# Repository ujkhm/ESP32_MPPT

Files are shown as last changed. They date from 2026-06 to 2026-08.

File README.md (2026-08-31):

# 微型發電機測試機 / Micro Generator Test Machine

以 **ESP32** 為核心的小型有刷直流發電機**特性量測機台**，不是 MPPT 控制器。

主動力 775 馬達把待測發電機帶到指定轉速後，依序量測連續安全電流、內阻與開路常數，再算出固定測試電阻上的功率曲線與可用轉速上限，上位機可存成 PDF 報表。

## 倉庫結構

```
micro-generator-test-machine
├── 3D_print_Component/   變速箱與機構 3D 模型（外殼 STL 另補）
├── BOM/                  元件清單與互動式 BOM
├── KiCad/                原理圖、PCB、Gerber
├── VSCode/esp32_code/    ESP32 韌體（PlatformIO）
└── Host computer/        免安裝上位機執行檔與說明
```

各資料夾內另有說明。

## 上位機

`Host computer/MicroGeneratorHost.exe` 免安裝。複製該資料夾到 Windows 電腦，雙擊執行，依畫面以藍牙連接下位機即可測試。詳見 [Host computer/README.md](./Host%20computer/README.md)。

## 目前狀態

- 電路與 PCB：完成（見 `KiCad/`、`BOM/`）
- 韌體量測流程：完成（安全電流、內阻、曲線）
- 上位機：完成（藍牙監控與 PDF 報表）
- 外殼：待補 STL

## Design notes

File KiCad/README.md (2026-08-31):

## KiCad

本專案電路使用KiCad 9做開發，無修改原理圖/PCB需求的可以直接使用資料夾內的Gerber.zip檔直接提交給板廠製板<br><br>
附上原理突及PCB快照<br>
[原理圖](images/KiCad.pdf)<br>
[PCB](images/KiCad_PCB.pdf)<br>
建議下載後用 PDF 檢視工具開啟。快照位於 `KiCad/images/`。
另有BOM表單位於BOM資料夾下[點我前往](../BOM/README.md)<br>
[回到主頁](../README.md)

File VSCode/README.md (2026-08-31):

# 韌體（ESP32 / PlatformIO）

下位機程式在 `esp32_code/`。開發環境為 PlatformIO，板子為 MH ET LIVE ESP32（`mhetesp32devkit`）。

量測流程：定速 → 安全電流階梯 → 內阻三點 → 功率曲線與 n_lim。細節見該目錄內的架構備忘。

[回到主頁](../README.md)

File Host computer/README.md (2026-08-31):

# 微型發電機測試機 — 上位機

本資料夾在 Git 上**只放免安裝執行檔與這份說明**。複製整個資料夾到 Windows 電腦即可使用，不必安裝 Python。

## 使用

1. 雙擊 `MicroGeneratorHost.exe`
2. 依畫面配對下位機藍牙（裝置名稱約為 `MicroGenerator-ESP32`），或手動選 COM 埠
3. 選擇報表儲存位置
4. 放好待測發電機，在機台上按 **START**
5. 測試結束後可存成 PDF

設定會寫在本機 `data/config.json`（不會進 Git）。鮑率 115200。

## 連線

| 項目 | 說明 |
|---|---|
| 方式 | 藍牙 SPP（Windows 虛擬 COM） |
| 鮑率 | 115200 |
| 資料 | 每行一個 JSON：`{"t":"live",...}` 約 200 ms 一次；曲線完成後另送 `{"t":"curve",...}` |

## 常見問題

**找不到藍牙裝置：** 下位機已開機、電腦藍牙已開。掃描需要幾秒。

**配對成功但連不上：** Windows 建立虛擬 COM 有時要等幾秒；逾時可改手動選埠。

**防毒攔截 exe：** 加入白名單後再執行。

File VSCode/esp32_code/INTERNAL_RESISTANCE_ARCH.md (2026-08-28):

# 發電機內阻模組總架構（實作備忘，無程式碼）

適用：micro generator 韌體；有刷機當發電機。  
與《安全電流模組》共用發電側負載開關與 INA232，但目的不同：這裡要的是短時間、同一轉速下的戴維寧內阻，不是十幾分鐘的連續電流。  
實作時再寫程式。本文只定量法、流程、對接與安全邊界。

**2026-08-27 硬體變更**：發電機到 INA232 之間串了一顆 SS54 蕭特基二極體做防反接保護（鱷魚夾接反時直接不導通，不會燒 INA232）。這顆二極體有隨電流變化的順向壓降，INA232 量到的電壓會比發電機端子的真實電壓低一截，已在韌體端補償（見 `settings.h` 的 `ss54_compensate_voltage_V()`），本文件下面提到的「Voc」「V」都是指補償後、代表發電機端子的真實值，不是 INA232 的原始讀數。電流量測不受影響。

---

## 1. 模組要做什麼

在主動力定速、發電側可開路／可接一顆已知電阻的前提下，量出端子上看起來的內阻 R_th（歐姆）。

這個 R_th 給後級用來：

- 算各轉速的電壓、電流、功率曲線（不必功率型可調電阻）
- 預估「下一檔轉速若接上同一電阻會有多大電流」，供安全電流模組決定還能不能加轉
- 熱穩後可再量一次 R_th_hot，給安全電流估銅溫（可選）

測到的不是萬用表停轉時的電樞直流電阻，也不是電感或感抗。是「這個轉速、這筆電流附近、從感應電勢到 INA 量電壓那個點」的等效串聯電阻，裡面會有銅線、電刷、接線，以及分流電阻（若電壓是在分流之後量的）。對計算圖來說，要的就是這一包，不必拆開——但要在文件裡寫死「包到哪裡」，前後一致。

一次識別建議在數個轉速各量一筆，得到 R_th(n)。第一近似可當常數；高轉明顯變大再插值。不要用交流電橋、也不要把感抗加進這個歐姆數。

---

## 2. 物理方法（精簡）

同一轉速必須量到兩個狀態：

1. 開路：電流約為零，電壓＝開路電壓 Voc，當作該轉速的 E。
2. 帶載：接上已知電阻 R_L，電壓 V、電流 I。

則

R_th ＝（Voc － V）／ I

等價寫法：R_th ＝ Voc／I － R_L,eq

R_L,eq 必須是「INA 看到的電壓除以電流」那一側的等效負載（已知水泥電阻 ± 配線；分流要不要算進 R_th 取決於 INA 電壓點在分流前還是後）。用同一顆 INA、同一套接線，不要開路用三用電表、帶載用 INA，否則兩點不在同一端子。

為什麼能成立：定速時發電機像電壓源加串聯電阻。電感不進平均值。電刷壓降會被這次的電流「折進」R_th，所以這筆 R_th 只對「接近這次 I」的負載準；電流差一個數量級時會有誤差，這是方法極限，不是實作 bug。

停轉用電表量電樞：只能當對照，不能當運轉內阻。停轉沒有換向、電刷膜不同，通常會偏小。

---

## 3. 和安全電流模組怎麼分工

內阻要快：每檔轉速應在「電氣穩定＋定速恢復」後立刻取樣，然後斷開負載，避免電機發熱把 R_a 量成另一個溫度。  
安全電流要慢：同一電阻上泡十幾分鐘看電流下垂。

建議上電後的總順序：

1. 主動力起動、調參、穩調。
2. 開路掃幾個轉速的 Voc（電流近零，幾乎不燒電機）。
3. 用 Voc 與硬電流天花板選／核對測試電阻：即使內阻當零，I 也不會超過 Voc／R_L。不滿足就換更大電阻或降低識別轉速，禁止猜一個很小的電阻去撞。
4. 內阻識別（短脈衝帶載）。
5. 安全電流識別（長期浸泡）。此時已有 R_th，預估下一檔電流可以準很多。
6. 之後守護電流；算曲線用 Voc(n) 與 R_th(n)。

負載 GPIO 只應有一個主人（建議：獨立的「負載閘」小介面，或暫由安全電流模組持有腳位）。內阻模組只請求「開路」或「接通測試電阻」，禁止兩個狀態機同時搶同一支腳。上電與急停仍是斷開為安全。

識別期間兩者都要遵守硬電流天花板。內阻脈衝再短，超流也要立刻斷。

---

## 4. 在整機裡的位置

與安全電流相同：不驅動主動力 PWM，不讀光柵，不直接操作 INA 匯流排。

- 讀：穩調旗標、現在轉速、目標轉速、故障、INA 電壓電流、硬電流上限／I_cont（若已有）。
- 寫：自己的 Voc、V、I、R_th、是否可信、目前轉速點。
- 請求：改目標轉速；請求負載通斷。
- 啟動：START 之後、調參完成、穩調為真。調參中負載必須斷開。

任務：可與安全電流同一個低優先權任務用「總識別狀態機」串起來，或分開兩個階段函式、同一任務依序呼叫。不要為內阻再開高優先權任務。

---

## 5. 對接 settings.h 資料中樞

照抄現有模組：自己的結構體、自己的自旋鎖（若與安全電流合併成「發電識別」一個結構，就共用那一顆鎖，不要拆成兩顆又互相等）。跨模組只走 get/set。鎖內禁止序列埠、延時、快閃。結果鎖外寫入記憶體。

建議欄位語意（名稱實作時再定）：

結果：R_th（歐姆）、對應轉速、對應電流、Voc、帶載 V、帶載 I、是否可信、測試電阻標稱歐姆。  
若多轉速：一組小表（轉速、R_th、Voc），外加「有效筆數」。  
執行期：階段、是否等待穩調、是否已請求接通、本點逾時。

誰寫誰讀：本模組寫結果；安全電流、曲線計算、畫面、序列埠只讀。目標轉速在識別中可改；識別結束不要改。

快閃：可存 R_th 表與當時的電阻標稱。電阻常數一改，舊表作廢。R_th 隨溫度變，沿用冷態表去算熱機曲線會偏小（電流估偏大，安全上偏保守，曲線功率會偏樂觀——畫圖時要知道）。

故障：內阻識別失敗（開路電流不是零、帶載電流太小、算出負電阻、超流、穩調逾時）可單獨故障碼，鎖定規則與安全電流同一套（斷負載、斷主動力、重開機）。也可以設定「內阻失敗則不准進入長期電流識別」。

---

## 6. 彈性設定

測試電阻：與安全電流用同一顆標稱歐姆。沒有第二顆可變電阻。

負載 GPIO：是否啟用、腳位、極性、接通／切斷後等待。關閉 GPIO 時無法自動開路，內阻法缺 Voc 與 V 兩點中的一點，此模式預設應拒絕內阻識別（除非人手動保證能開路，另開危險常數）。

轉速點：幾個識別轉速（低、中、高），須在可讀轉速與飛車門檻之間。可先只做一個轉速，表的長度用常數。

時間（都要短，相對安全電流）：

- 開路電氣穩定。
- 接通後等定速恢復（負載一上，轉速會掉，必須等穩調再取樣，否則 Voc 與 V 不是同一轉速，R_th 會錯）。
- 帶載取樣窗（穩調後再平均若干筆 INA）。
- 取樣結束立即切斷。
- 單點總逾時。

安全：

- 硬電流天花板（同安全電流，低於 0.8 A）。
- 開路電流上限：超過視為負載黏住。
- 帶載電流下限：低於視為沒接上。
- R_th 合理範圍（例如大於分流一個數量級、小於某上限）。超出當失敗，不要寫入可信結果。
- 預檢：Voc／R_L 必須小於硬天花板，否則本轉速不准接通。

策略：

- 每點要不要重複量兩三次取中位（抑制換向漣波與 INA 抖動）。
- 是否在安全電流熱穩之後再量一筆 R_th_hot（可關）。
- 每次開機重測或沿用舊表。

---

## 7. 狀態機流程（每一個轉速點）

上電：負載斷開。

P0 等待：調參結束、穩調曾出現過，進入第一個轉速點。

P1 設轉速：負載保持斷開，寫入該點目標轉速，等穩調。逾時失敗。

P2 開路取樣：確認電流近零，平均 Voc。失敗則鎖定。用 Voc／R_L 預檢電流；過大則跳過該點或整段失敗（常數決定，預設整段失敗較安全）。

P3 接通並等定速：請求接通。轉速掉再拉回。等穩調與電氣穩定。此期間已在帶載，電流一超硬上限立即切斷鎖定。

P4 帶載取樣：平均 V、I。立刻請求切斷。I 過大已在 P3 處理；I 過大過小、V 接近 Voc（內阻算不出來或負載沒接上）則失敗。

P5 計算：R_th ＝（Voc － V）／ I。檢查正、落在合理範圍、且 Voc 約等於 V 加 I 乘 R_th。通過則寫入本點；否則本點作廢。

P6：若還有轉速點，負載已斷，回到 P1。全部完成則發布「內阻可信」，交給安全電流或守護。

全程任一故障／急停：先切斷負載，再整機鎖定。

---

## 8. 安全規則（寫程式時不可省略）

1. 未知 R_th 時，用 Voc／R_L 當電流上限估計（把內阻當零）。這是接通前唯一準的保守估計。
2. 帶載取樣必須等穩調恢復。開路與帶載轉速不一致是內阻量錯的第一常見原因。
3. 取樣完立刻開路，不要在內阻識別裡做熱浸泡。
4. 禁止短路當第二點（I 約 Voc／R_th，高轉會燒電機也會飽和 INA）。
5. 開路電流不是零不准進入帶載。
6. 硬天花板在接通後第一筆 INA 就要查，不要等平均結束。
7. 與安全電流搶 GPIO 時，內阻階段未結束，安全電流不准接通去做長泡。
8. 算出的 R_th 供畫圖與預估；真正不燒電機仍靠硬電流與 I_cont，不要只信內阻公式。

---

## 9. 誤差大概會從哪裡來（方便解讀結果）

- 轉速沒對齊：R_th 可正可負、亂跳。
- 帶載太久發熱：R_th 偏大。
- 電刷壓降：輕載與重載不是同一條直線；識別電流應接近日後常用電流。
- INA 開路時電壓準、電流應近零；帶載時分流 0.1 歐若被算進或漏算，會有固定偏差，接線定義要前後一致。
- 單點、冷機：畫高轉熱機功率會偏樂觀。多轉速表加可選熱態點可縮小。

合理預期：轉速對齊、短脈衝、電阻已知時，R_th 大約到幾個百分點到十幾百分點，夠拿來畫第一版曲線與預估電流。不夠當精密電橋。

---

## 10. 畫面與除錯（最少）

階段、目標轉速、Voc、V、I、算出的 R_th、本點是否通過。  
序列埠每個轉速點一行即可。

---

## 11. 建議實作順序

負載閘通斷與急停已可用之後：只做單一中低轉速的開路→短接通→計算，序列埠印 Voc、V、I、R_th，用人核對是否約等於（Voc－V）／I 且為正。  
再加「接通前 Voc／R_L 預檢」與硬電流。  
再加多轉速表與記憶體。  
最後接到安全電流的「下一檔電流預估」。

---

## 12. 一句話

發電機內阻＝同一轉速先量開路電壓、再短時間接已知電阻量 V 與 I，R_th＝（Voc－V）／I；等定速恢復才取樣，取完立刻開路。不是停轉電表，也不是長期泡負載。結果進資料中樞，給曲線計算與安全電流預估用。

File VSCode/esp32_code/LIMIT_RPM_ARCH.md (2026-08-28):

# 極限轉速模組總架構（實作備忘，無程式碼）

適用：micro generator 韌體。  
本模組**不是**物理／機械轉速極限，也不是開路一路加轉去撞飛車。  
要的是：在電流、電壓天花板之下，**再提高轉速也無法再增加可取出的輸出電功率**（或最大功率點已不合法）的那個轉速。用 k_e、R_th、I_allow、V_allow **計算**。  
實作時再寫程式。

---

## 1. 計算之前必須承認的物理

Ke 與內阻若當常數，最大電功率

P_mpp ＝ Voc² ／（4 R_th）

Voc 約正比於轉速，故 P_mpp 約正比於轉速的平方。**發電機自己不會「功率飽和」。** 轉愈快理論峰值愈大。

會封頂的是外加限制：

- 電流天花板 I_allow（硬上限與 I_cont 的較嚴者）
- 電壓天花板 V_allow（INA／後級耐壓，留餘量）
- 測試電阻固定時，電流 I ＝ Voc／（R_th＋R_L），先碰到 I_allow 功率就被卡死

本模組只算這些電氣封頂轉速。飛車門檻仍只當毀機牆，不拿來當「測到的極限」。

---

## 2. 要算的三個轉速（由嚴到寬看）

k_e ＝ Voc／n（與內阻模組同一套開路點，單位一致即可，最後輸出 RPM）。

**A. 固定測試電阻上的功率封頂（這台機預設最有用）**

電阻固定時 P ＝ I² R_L，I 隨轉速漲。I 一碰到 I_allow，這顆電阻上的輸出功率就不能再靠加轉速增加：

n_rl ＝ I_allow ×（R_th ＋ R_L）／ k_e

P_sat,rl ＝ I_allow² × R_L

這就是「負載不變、只調轉速」時輸出功率飽和的轉速。安全電流階梯的最高檔不得高於 n_rl。

**B. 最大功率點開始不合法（可變負載／日後 MPPT）**

I_mpp ＝ Voc／（2 R_th）＝ I_allow 時：

n_knee ＝ 2 × I_allow × R_th ／ k_e

低於 n_knee：可以跑 R_L≈R_th，P_avail＝P_mpp，隨轉速平方成長。  
高於 n_knee：合法工作點只能 I≤I_allow，P_avail＝I_allow×（Voc－I_allow×R_th），仍隨轉速**線性增加**，還不是真正封頂。對外可稱為「最大功率點極限轉速」，不要寫成「功率已飽和」。

**C. 電壓與電流同時頂滿（真正的功率飽和）**

端子上要同時 V≤V_allow、I≤I_allow，感應電勢最多到 V_allow＋I_allow×R_th：

n_sat ＝（V_allow ＋ I_allow × R_th）／ k_e

P_ceil ＝ V_allow × I_allow

再快，可取出功率不能超過 P_ceil。注意：此時開路電壓 Voc＝k_e×n_sat 已經高於 V_allow。若負載 GPIO 會斷開、INA 一直掛在匯流排上，開路就會超壓。因此：

- 允許長時間開路：操作轉速還要 ≤ n_voc ＝ V_allow／k_e（比 n_sat 更嚴）。在 n_voc 功率往往**尚未**封頂。
- 保證不斷開且 INA 只看到帶載電壓：才可以用 n_sat 當功率飽和轉速。

本機預設會開路，對外發布的 n_lim 取 min(n_rl, n_knee, n_voc, 人為飛車降額)。n_sat 可當除錯計算值，預設不當操作上限。

**I_allow 從哪來（可以、而且應該由模組給）：**

I_allow 不是銘牌常數。優先用安全電流模組發布的 I_cont；尚未測出前，用硬電流天花板（低於 INA 0.8 A 那層）。兩者同時存在時取較嚴。

這會形成「n_lim 需要 I、量 I 又希望不超過 n_lim」。解法是算兩次，不要一次解聯立：

1. I_allow＝硬電流 → 算出暫定 n_lim。安全電流階梯只准走到這裡。
2. 安全電流用下垂法得到 I_cont（通常比硬電流小）→ 再算一次 n_lim，只准收緊。

不要用銅損公式去「算」I_cont 來取代浸泡（缺熱阻、缺鐵損，數字會假準）。安全電流模組量到的才是電流天花板；極限轉速模組只負責把它代入轉速公式。

缺數時：沒有 R_th 不算 n_rl／n_knee／n_sat；沒有 I_cont 就用硬電流當 I_allow；沒有 V_allow 則 n_voc、n_sat 不存在。連硬電流與 k_e 都沒有則 n_lim 暫用人為天花板，標不可信。

---

## 3. 模組要做什麼

本模組是**計算器＋發布器**，不是爬升試驗機。

輸入（只讀別人已發布且可信的結果）：若干開路點得到 k_e（一點也行，兩點可檢查 Voc 是否線性）、R_th、I_allow、V_allow、R_L 標稱。  
輸出：n_rl、n_knee、n_sat、n_voc、對外 n_lim、原因碼、是否可信。

不改目標轉速去找極限。不接通負載。不把 PWM 頂滿當終點（那是驅動能力，不是發電功率飽和）。若日後要「主動力也功率飽和」那是另一條可選夾限，需要驅動側電流或模型，本版不做。

k_e 從哪來：內阻模組（或極短的開路取樣）在中低轉、已穩調、負載斷開時留下的 Voc 與 n。本模組不要為了算 k_e 往極限轉。Voc 明顯不隨轉速正比時（兩點 k_e 差太多），標不可信，n_lim 只用人為天花板。

算完之後：識別總管把後續目標轉速夾在可讀最低轉與 n_lim 之間。內阻若尚未做完，先做內阻再呼叫本模組重算一次（I_cont 出來後再重算，只准把 n_lim 收緊）。

---

## 4. 和另外兩模組的總順序

1. START → 定速穩調。
2. 內阻（中低轉開路 Voc 得 k_e，短脈衝得 R_th）。可順便多一個開路點核對線性。
3. 本模組第一次計算：I_allow＝硬電流，得到暫定 n_lim（至少有 n_rl、n_knee、n_voc）。
4. 安全電流長期浸泡：階梯不得超過暫定 n_lim。
5. I_cont 若比硬電流更嚴，本模組重算，n_lim 只收緊。
6. 守護：電流上限與 n_lim 同時生效。

不再把「開路爬升找 PWM 飽和」放在內阻前面。人為飛車降額仍是所有目標轉速的硬夾限，與本模組並行。

---

## 5. 對接 settings.h 資料中樞

自己的結構（或併入發電識別同一把鎖）。只讀內阻與安全電流的結果，不寫他們的欄位。跨模組 get/set。鎖內禁止序列埠、延時、快閃。

結果欄位語意：k_e、n_rl、n_knee、n_sat、n_voc、n_lim、P_sat（對應固定電阻或 P_ceil，註明哪一種）、限制原因（電阻電流封頂／最大功率點不合法／開路耐壓／人為天花板／資料不足）、是否可信、計算時用的 R_th／I_allow／R_L。

誰寫目標轉速：仍由識別總管夾限；本模組只發布 n_lim。

快閃：可存 n_lim 與當次用的 R_L、R_th、I_allow。任一常數或識別結果變了必須重算，不可沿用。

本模組沒有「找到極限」這種故障。資料不足＝不可信＋用人為天花板。只有讀到的 Voc 已超過 V_allow 才請求鎖定（那是量測點已經超壓，不是算錯）。

不需要為本模組去加測速跳變計數——那是物理爬升才要的，本版不做爬升。

---

## 6. 彈性設定

- V_allow（伏）、人為最高轉速（低於飛車）。
- 對外 n_lim 要不要把 n_knee 算進去（MPPT 要；只做固定電阻曲線可以只取 n_rl 與 n_voc）。
- 是否計算並顯示 n_sat（預設只顯示、不當夾限）。
- k_e 兩點相對差超過多少視為非線性、結果不可信。
- I_cont 尚未存在時是否用硬電流先算（預設要，否則安全電流沒有階梯上限）。

---

## 7. 流程（計算，不是爬轉速）

C0 等人為天花板已存在。

C1 讀取至少一個可信開路點 → k_e。失敗則 n_lim＝人為天花板，不可信，結束。

C2 若有 R_th 與 R_L：算 n_rl。若有 R_th：算 n_knee、n_sat。永遠可算 n_voc。

C3 n_lim ＝ 所有「啟用且有數字」的操作上限與人為天花板的最小值。寫入原因（誰最小）。

C4 安全電流或 I_allow 更新後從 C2 重算，新值不得大於舊 n_lim。

全程負載狀態由別模組負責；本模組不碰 GPIO。

---

## 8. 安全規則

1. 算出的 n_sat 高於 n_voc 是公式如此，不是 bug。開路平台不准用 n_sat 當 keep_rpm。
2. n_lim 只收緊不放寬。
3. R_L 或 I_allow 改了必須重算。
4. 計算值仍受飛車降額夾住。公式再大也不能讓目標轉速靠近飛車。
5. 不要用 P_mpp∝n² 的外推去「證明還能加轉」，那正是天花板要擋住的事。

---

## 9. 畫面與除錯

顯示 n_lim、原因、k_e、n_rl、n_knee、n_voc。可選 n_sat 標成「帶載功率封頂、開路勿用」。  
序列埠一行印齊輸入（Voc、n、R_th、I_allow、R_L）與輸出，方便手算核對。

---

## 10. 建議實作順序

內阻能產出 k_e 與 R_th 之後，先做純函數：代入假數字手算對得上再接資料中樞。  
接到硬電流算出暫定 n_lim，給安全電流當階梯頂。  
I_cont 進線後再收緊一次。

---

## 11. 一句話

極限轉速用算的：固定電阻上 I 碰到 I_allow 的轉速就是這台機輸出功率封頂；可變負載再加「最大功率點不合法」與開路耐壓。發電機模型本身功率不飽和，也不用去測物理轉速極限。

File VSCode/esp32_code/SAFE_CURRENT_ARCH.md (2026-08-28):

# 安全電流模組總架構（實作備忘，無程式碼）

適用：micro generator 韌體；有刷機當發電機。  
前提：主動力已能定速；發電側由 INA232 讀電壓／電流；本模組負責「找出連續安全電流」並在之後當硬上限。  
實作時再寫程式。本文只定流程、對接方式、彈性設定與安全邊界。

**2026-08-27 硬體變更**：發電機到 INA232 之間串了一顆 SS54 蕭特基二極體防反接。電流讀值不受影響(判斷通過/上限的下垂比例、硬電流天花板都以電流為準，完全不用改)；本模組唯一會讀的電壓量(`safe_oc_voltage_V`)已在韌體端補償二極體順向壓降，代表發電機端子的真實 Voc，見 `settings.h` 的 `ss54_compensate_voltage_V()`。

---

## 1. 模組要做什麼

兩件事，同一個模組，兩個階段：

1. 識別：負載電阻固定，只改轉速，每個轉速長期定住，用輸出電流是否還在掉、以及硬上限，找出連續安全電流 I_cont。
2. 守護：識別結束後（或已從記憶體讀到舊值），任何發電側電流超過 I_cont（再加一層硬天花板）就立刻切斷負載並走既有故障鎖定。

測到的 I_cont 是「這顆測試電阻、這套散熱、這條 I 約正比於轉速的負載線」上的連續電流，不是銘牌上處處通用的額定電流。允許把它當後續所有轉速／負載的保守天花板。換電阻或換散熱要重測。

I_cont 要發布給極限轉速模組當 I_allow（與硬電流取較嚴）。安全電流識別期間極限轉速只有「硬電流算出來的暫定 n_lim」；I_cont 產出後極限轉速會重算並收緊。本模組階梯讀暫定 n_lim，不要等 I_cont 才開始（否則互相等）。

不測扭矩、不算效率、不掃可變電阻、不在識別中追求最大功率點。高轉若公式顯示最大功率點電流已大於當前上限，該轉速只准開路或極輕載，不准把負載接到最大功率。

---

## 2. 物理方法（精簡）

固定電阻時，電壓與電流不是兩個獨立資訊（電壓約等於電流乘電阻）。長期定速能看到的是：電機變熱 → 內阻上升、磁鐵變弱 → 同一轉速電流慢慢下降。

判讀：

- 電氣先穩（毫秒～數十毫秒），再等熱穩（小馬達殼側常見十到二十分鐘）。
- 熱穩後，電流相對「電氣剛穩那一小段」只掉約百分之二到三、且已不再掉：這一檔通過，電流可當偏安全的連續值。
- 掉約百分之五到十才打平：當上限，取「上一檔通過」的穩態電流當 I_cont，本檔不當通過。
- 一直掉、不平、或碰到硬電流／硬電壓／飛車／無脈衝：立即斷負載，本檔失敗。

可選加強：熱穩後短暫切斷負載、量開路電壓（數秒內，別等它冷掉），再合上。用開路電壓與帶載電流估算熱態內阻，換算銅線溫升。沒做這一刀，就不要宣稱量到繞組溫度，只宣稱量到電流下垂。

殼溫若以後有感測器可當輔助門檻（例如環境以上四十度就停）。沒有溫度感測時，以電流下垂與硬電流上限為準。主動力馬達的熱會經聯軸器傳到發電側，殼溫不可當成發電繞組的唯一依據。

由低轉往上加一檔，兩檔之間若電機還很熱，要等冷回（或規定最短冷卻時間），否則熱會累積、看起來比較不耐流。I_cont 取最後一個「完全通過」檔的熱穩電流，不是失敗檔當下的電流。

---

## 3. 在整機裡的位置

本模組不驅動主動力 PWM，不讀光柵，不直接操作 INA232 匯流排。

- 讀：轉速穩調旗標、現在轉速、目標轉速、故障、INA 電壓電流是否有效、UI 是否已在運行。
- 寫：自己的狀態與識別結果；要換轉速時只改目標轉速，然後等穩調旗標再量。
- 切：發電側接到測試負載的 GPIO（若啟用）。預設斷開＝開路＝安全。任何故障、急停、識別結束、上電瞬間，負載都必須是斷開。
- 故障：與現有測速／PID 同一套鎖定（斷主動力 PWM、需重開機）。斷負載必須發生在鎖定當下，不可等下一個迴圈。

啟動時機：按 START、主動力定速且穩調旗標為真、且未在自動調參之後。調參期間本模組只許保持負載斷開。按 START 當急停時，本模組與其他人同一條急停路徑，先斷負載。

任務建議：Core 1、優先權低於畫面、高於 Arduino 迴圈；週期不必快（識別時數百毫秒輪詢即可）。守護電流若擔心週期太慢，可在 INA 任務裡只做「超硬上限就升起旗標」，本模組或急停路徑負責斷負載。不要在 INA 任務裡做長時間狀態機。

---

## 4. 對接 settings.h 資料中樞

完全照現有模組抄：

- 在 settings 宣告本模組自己的結構體，執行期狀態與識別結果放這裡。
- 在 settings 原始碼檔加一顆專用自旋鎖，與測速、PID、INA、UI 分開，避免量測卡住控制迴路。
- 每個純量欄位用既有巨產生執行緒安全的讀寫函式。跨模組只准用這些函式，不准直接碰別人的欄位。
- 一次要寫「負載已切斷＋識別失敗＋故障碼」這種彼此相關的事實，用既有的鎖守衛包住自己結構的整段；需要同時改測速側故障鎖定時，遵守「同一時間只持一顆鎖」：先改完自己的結構並解鎖，再呼叫測速側既有的故障／急停流程，或由主程式統一急停、本模組只提供「請切斷負載」的函式給急停呼叫。
- 鎖內只能幾行欄位讀寫。禁止在鎖內做序列埠、延時、快閃記憶體。要存識別結果：先在鎖內複製到區域變數，解鎖後再寫入（寫法對齊 PID 的載入／儲存）。
- 新增故障碼（例如發電過流、識別超溫／電流下垂超標、負載 GPIO 未就緒、INA 在識別中掉線）。這些碼與現有飛車、無脈衝、急停並列，鎖定後同樣要重開機。
- 識別用的常數（電阻歐姆、轉速階梯、下垂百分比、熱穩時間、硬電流）放 settings 檔開頭的常數區，與飛車轉速、分流電阻同一層，方便改機台時只改一處。
- 腳位放腳位檔：負載接通 GPIO 與主動力 PWM、測速、INA 並列。不要把腳位寫死在模組內部。

建議由本模組擁有的欄位（名稱實作時再定，語意要有）：

執行期：模組階段、負載是否接通、本檔開始時間、本檔電氣穩態電流、本檔熱穩電流、電流下垂比例、是否已請求改目標轉速、等待穩調中。

結果：I_cont（安培）、測得時的電阻歐姆、測得時通過的最高轉速、識別是否完成且可信、硬電流天花板（通常小於 INA 飽和的 0.8 安培）。

除錯：本檔序號、最後一次開路電壓、最後一次帶載電壓／電流。這些給畫面與序列埠，不是控制依據。

誰寫誰讀：

- 本模組寫自己結構的全部執行期與結果。
- 畫面、序列埠、日後 MPPT 只讀 I_cont、識別完成、負載接通、階段。
- 目標轉速：本模組在識別中可以改；守護階段不要改轉速。
- 穩調旗標、現在轉速、故障：只讀。
- INA 電壓電流：只讀；發現過流時本模組切斷負載並請求故障鎖定，不在 INA 結構裡塞邏輯。

快閃記憶體：識別成功後可存 I_cont、電阻、通過最高轉速、已識別旗標。開機載入後若「已識別」為真，可跳過識別直接進守護（用常數決定每次開機都重測還是沿用）。電阻常數若與記憶體裡存的電阻不一致，視為設定已改，必須重測，不可沿用舊 I_cont。

---

## 5. 彈性設定（實作前用常數決定，不必做選單）

下列每一項都要能在改常數後重編即換行為，不要寫死在狀態機裡。

測試電阻

- 歐姆值（已知水泥電阻）。用於核對電壓／電流是否合理，以及可選的熱態內阻。
- 電阻瓦數僅供註解與人為檢查，韌體不必算電阻會不會燒；但帶載功率若明顯超過註解瓦數，可當警告事件，仍以電機電流為切斷依據。

負載 GPIO

- 是否啟用。關閉：視為負載永遠由人手動接上，模組只負責「沒穩調不准開始計時、過流只拉故障、無法自動開路」。此模式較危險，預設應為啟用 GPIO。
- 腳位編號（建議用目前預留給後級的腳，與主動力 PWM 分開；不要占用 START、I2C、測速）。
- 接通為高或為低。上電與故障時的安全電平必須是「斷開」。
- 接通後額外等待（繼電器彈跳、接點穩定）才開始記電氣穩態。
- 切斷後若要量開路電壓，再等電氣穩定才讀 INA。

轉速階梯

- 起始轉速、每檔增量、最高轉速。最高轉速不得高於現有飛車門檻，並留餘量。
- 起始轉速不得低於現有可讀轉速門檻。
- 是否在每檔帶載前先做一次開路電壓（建議開，作為該轉速的 E，也方便事後算內阻）。

時間

- 電氣穩定時間（短）。
- 熱穩定最長時間（長，分鐘級）。
- 熱穩定判定：電流在一段觀察窗內變化小於某比例或某安培，才算打平。
- 檔與檔之間的最短冷卻時間（可為零；預設建議非零）。
- 可選開路快照最長時間（數秒，逾時視為失敗並斷負載）。

電流與下垂

- 硬電流天花板（必須低於 INA 量程 0.8 安培，建議約 0.55～0.65 安培，且可再被「已識別的 I_cont」收緊）。
- 通過：下垂上限（約百分之二到三）。
- 當上限、本檔不通過：下垂上限（約百分之五到十）。
- 絕對下限電流：太小代表負載沒接上或 INA 無效，應失敗而不是當成很耐流。
- 電壓／電流與標稱電阻的一致性檢查（例如算出的等效電阻偏離標稱太多，當接線錯誤）。

識別策略

- 每次開機都測，或記憶體已有且電阻未改則跳過。
- 是否啟用開路快照估銅溫（預設可關，先做下垂法）。
- 識別失敗時：只斷負載並鎖定，不要嘗試自動換下一檔硬闖。
- 守護是否在識別成功前就生效：識別過程本身必須套用硬天花板；I_cont 在尚未產生前，硬天花板就是唯一上限。

畫面與序列埠

- 是否在識別中顯示倒數／本檔轉速／電流／下垂。
- 除錯列印間隔。不要在鎖內印。

沒有的感測器

- 殼溫感測：常數關閉則整條溫度門檻不存在，不假裝有溫度。
- 日後若加溫度，只新增欄位與一個「超溫切斷」，不要改狀態機主幹。

---

## 6. 狀態機流程

上電：負載 GPIO 設為斷開（若啟用）。載入記憶體。階段＝待機。

按 START 之後（馬達與測速已啟動）：本模組任務活著，但在穩調為假或調參中時，負載保持斷開，不做識別。

A. 待機

- 若設定為沿用舊 I_cont 且記憶體可信：進入守護。
- 若需識別：等穩調為真且調參完成，進入「準備下一檔」（第一檔用起始轉速）。

B. 準備下一檔

- 負載斷開。
- 把目標轉速設成該檔轉速。
- 進入「等定速」。逾時（目標轉不到、故障）→ 失敗鎖定。

C. 等定速

- 只讀穩調旗標。為真後進入「開路取樣」（若該功能關閉則直接「接通負載」）。

D. 開路取樣（可選）

- 確認負載斷開，等電氣穩定，讀電壓當本檔開路電壓、電流應接近零。
- 電流明顯不是零：視為負載 GPIO 黏住或接線錯，失敗鎖定。
- 開路電壓異常高（接近或超過後級耐壓想像值）或異常低：失敗或跳過本檔（常數決定），預設失敗鎖定較安全。

E. 接通負載

- 拉 GPIO 接通，等接點穩定＋電氣穩定。
- 讀電流。超過硬天花板 → 立刻斷開並鎖定。
- 等效電阻與標稱差太多 → 斷開並鎖定。
- 記下「電氣穩態電流」，開始熱穩計時。進入「熱浸泡」。

F. 熱浸泡

- 週期讀電流（及電壓）。任何一次超過硬天花板 → 斷開鎖定。
- 飛車、無脈衝、急停、INA 掉線、穩調變假：斷開，若是急停／故障走既有鎖定；若只是短暫失穩可先斷負載再回到等定速（常數決定，預設走鎖定較單純）。
- 電流在觀察窗內打平：算下垂比例，進入「本檔判定」。
- 熱穩逾時仍未打平：視為不通過（持續發熱），斷開，I_cont 用上一檔通過值；若連第一檔都未通過，I_cont 不成立，鎖定。

G. 本檔判定

- 先斷開負載（進入判定就不該繼續加熱），可選立刻做熱態開路快照。
- 下垂小：本檔通過，更新「目前通過的 I_cont 候選」為本檔熱穩電流。若還有下一檔且下一檔預估電流（用本檔開路電壓與電阻粗估，或用電流約正比轉速外推）不會超過硬天花板：冷卻等待後回到準備下一檔。若預估已超硬天花板或已達最高轉速：識別成功，寫入記憶體，進入守護。
- 下垂中等：識別成功，I_cont＝上一檔通過電流（第一檔就中等則失敗，不要把過熱檔的電流當額定）。進入守護或鎖定（第一檔失敗必鎖定）。
- 下垂大或未打平：同上，更乾脆當失敗檔。

H. 守護（識別成功或沿用舊值之後）

- 負載 GPIO 是否接通改由後級（MPPT／手動）決定；本模組不管誰接通，只看 INA 電流。
- 電流大於 min(I_cont，硬天花板) 持續若干筆（避免雜訊一筆就跳）→ 斷負載＋故障鎖定。
- 本模組不再改目標轉速。

I. 失敗／與整機故障

- 負載必斷。
- 請求與現有急停相同等級的鎖定（主動力 PWM 歸零、階段進故障、需重開機）。
- 畫面顯示安全電流故障碼。

---

## 7. 安全規則（寫程式時不可省略）

1. 上電、重設、任務尚未跑：GPIO 方向與電平先進入斷開，再做別的初始化。
2. 沒有穩調、調參中、故障中：禁止接通負載。
3. 切斷負載的函式必須可重入、可從急停路徑呼叫、內部先拉腳位再改自己的「已接通」旗標。
4. 識別中途禁止把電阻當可變；軟體沒有「再加一檔更重的負載」。要換電阻只能停機改硬體並改常數。
5. 預估下一檔電流用「本檔電流乘轉速比」或「開路電壓除以（內阻加電阻）」皆可，缺內阻時寧可高估電流、少測一檔，不可低估然後硬上。
6. INA 未在線或資料無效：視同無法保護，不准接通負載；若已接通則切斷並鎖定。
7. 硬天花板永遠生效，包含識別第一秒。I_cont 只能把上限收得更緊，不能放寬過硬天花板。
8. 固定電阻模式的守護在「人把負載手動短路」時仍可能來不及；GPIO 啟用時至少能斷開測試電阻。手動模式必須在文件與畫面標明無自動開路。
9. 不要用計算出來的最大功率點電流當識別目標。識別走階梯＋下垂，不是走最大功率。
10. 與現有飛車、無脈衝看門狗並存，不取代它們。發電側過流是多出來的一條。

---

## 8. 畫面與除錯（最少）

識別中：階段名稱、目標轉速、現在轉速、是否穩調、負載通斷、電流、本檔下垂、熱穩經過時間。  
守護中：I_cont、硬天花板、即時電流。  
故障：新故障碼文字。  
序列埠：每檔通過／不通過一行（轉速、開路電壓、穩態電流、熱穩電流、下垂、結果）。禁止把 INA 原始值每毫秒印爆。

---

## 9. 建議實作順序（開始寫程式時）

先做負載 GPIO 的安全斷開與急停連動，用假條件確認腳位不會在開機時誤接通。  
再做守護：硬編碼一個很小的電流上限，用手轉或低轉帶載確認會斷開並鎖定。  
再做識別狀態機，熱穩時間先改成幾十秒當乾跑，確認階梯、穩調等待、下垂計算、記憶體寫入。  
最後把熱穩時間改回分鐘級，用真實水泥電阻跑一次完整識別。  
MPPT／降壓占空比等後級，只讀 I_cont 與「守護是否已啟動」，不要複製一套電流限制。

---

## 10. 一句話

安全電流模組＝固定電阻＋定速階梯＋先斷負載再判定下垂，找出保守 I_cont；全程 GPIO 能開路、硬電流低於 INA 飽和；結果進資料中樞給後級當天花板。不是通用額定銘牌，也不是最大功率掃描。

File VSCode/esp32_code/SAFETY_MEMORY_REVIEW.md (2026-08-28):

# 韌體記憶體與時間軸安全覆查報告

適用範圍：本次新增的 6 個模組(`measure_seq`、`safe_current`、`gen_resistance`、`curve_calc`、
`bt_telemetry`)＋對既有 `settings.h`／`motor_PID.cpp`／`speed_sensor.cpp`／`main.cpp`／
`board_ui.cpp`／`pins.h`／`RTOS.h` 的修改。

結論先講：**已用 PlatformIO 實際編譯成功**(見第 7 節數據)，**鎖的使用經逐一追蹤，全專案任何一條路徑都不會同時持有兩把鎖**(第 2 節)，**RPM 飛車／馬達通電看門狗／ESTOP 三道既有防線完全沒被修改或繞過**(第 4 節)，新增的「發電機斷線暫停」與「量測安全鎖定」兩個機制都是疊加在既有防線之上、不是取代。以下逐項說明依據，不是只有結論。

---

## 0. 修訂記錄

**2026-08-27　修正：定速目標曾被硬蓋成固定常數，導致調參完成後長時間震盪不收斂**

初版曾在 `motor_PID_init()` 裡加一行 `pid_set_keep_rpm(MEASURE_MIN_RPM)`，想讓每次開機的
量測起點是一個確定的數字。這個改動忽略了本機台的一個既有、在 `motor_PID.cpp` 開頭就
大量註解過的特性：**PWM→RPM 增益極不均勻**，sTune 自動調參是針對「開環階梯自然停下來
的那個轉速附近」做特性化，算出的 Kp/Ki 只在那個工作點附近有效。硬把 `keep_rpm` 蓋成
一個固定常數後，`begin_autotune()` 裡原本「`keep_rpm<=1` 時鎖存目前速度」的自我一致
邏輯被繞過(因為 `keep_rpm` 已經 >1)，於是調參完成、切入閉環的那一刻，系統被命令從
「剛特性化過的工作點」跳去「這個寫死的常數」，兩者可能差距不小，PID 用著在別的工作點
算出來的增益去追一個沒被特性化過的目標，在這種增益極不均勻的機台上就是實測會長時間
震盪不收斂的典型情境。

**修正方式**：拿掉那一行強制賦值，恢復原始「`keep_rpm` 鎖存自動調參當下的實際轉速」的
自我一致行為；`safe_current_reset()` 的第 0 檔目標也從固定常數改成讀取當下的
`pid_get_keep_rpm()`(新增 `safe_start_rpm` 欄位保存這個起點，供 `gen_resistance`／
`curve_calc` 之後取用，取代原本各自使用的 `MEASURE_MIN_RPM` 常數)。`MEASURE_MIN_RPM`
現在只當作事件訊息/報表備援下限的參考值，不再是任何地方拿去強制命令 PID 的目標。

第 3、4 節與第 8 節下方原本描述「定速在 `MEASURE_MIN_RPM`」的地方已一併更新用詞，但
為了不讓覆查記錄失真，沒有回頭改寫整份文件的敘事順序，只在對應段落加註更正。

**2026-08-27　新增：發電機防反接 SS54 二極體的電壓補償**

硬體上在發電機與 INA232 之間加了一顆 SS54 蕭特基二極體防反接。新增 `settings.h` 的
`ss54_compensate_voltage_V()`(純函式，無共享狀態、無鎖，不影響第 2 節的鎖分析)，
在 `safe_current.cpp`(開路 Voc)與 `gen_resistance.cpp`(開路 Voc、帶載 V)三個讀值點
補償二極體順向壓降。只動到「怎麼把 INA 讀數換算成發電機端子電壓」這一步，不影響任何
電流門檻判斷、狀態機轉移條件、鎖的使用方式；補償模型是近似值(校準範圍 0～0.6A，對應
本應用實際會用到的電流)，常數集中在 `settings.h` 開頭並附上如何用實測值校正的說明。

**2026-08-27　修正：`safe_current_reset()` 在 SAFE_CURRENT 真正開始前太早呼叫，導致
安全電流一開始就把轉速拉到 0、觸發無脈衝看門狗**

上一輪修正把「安全電流第 0 檔的起點」從固定常數改成讀取 `pid_get_keep_rpm()`，方向是對的，
但呼叫的**時機**錯了：`safe_current_reset()` 原本只在 `measure_seq_task()` 剛啟動時呼叫一次
(見第 3.1 節)，那個時間點開環爬升、自動調參都還沒開始，`keep_rpm` 當下多半是 0 或
NVS 殘留的舊值。這個(錯誤的)0 就被存進 `safe_start_rpm`，一路帶到 `MEAS_SAFE_CURRENT`
階段才被 `SAFE_PH_PREP` 拿去下令 `pid_set_keep_rpm(0)`──實測現象正是「進入安全電流測試
後轉速逐漸變慢、歸零、最後跳 `FAULT_NO_PULSE_TIMEOUT`」，是既有無脈衝看門狗正確攔下來的
(這道防線本身沒有問題，是量測序列自己下錯指令)。

**修正方式**：在 `measure_seq.cpp` 的 `case MEAS_MIN_SPEED_HOLD:` 分支裡，確認
`speed_get_speed_stable()` 為真的那一刻(這才是「自動調參後系統自然停下來的轉速」第一次
真正確立的時刻)才呼叫 `safe_current_reset()`，取代開機時那次過早的呼叫(該次呼叫繼續保留，
只是它捕捉到的值現在會被這裡蓋掉，不影響正確性)。斷線暫停後的續測路徑
(`handle_link_lost_state()`)本來就是在 `wait_for_resume_stable()` 成功後才呼叫
`safe_current_reset()`，時機一直是對的，不需要修改，現在兩條路徑的時機終於一致。

---

## 1. 記憶體分析

### 1.1 只用靜態配置，沒有動態記憶體

- 新增的 6 個模組**沒有任何一處呼叫 `malloc`／`new`／Arduino `String`**。字串一律用固定大小的 `char[]` 緩衝區 + `snprintf`/`vsnprintf`。
- `bt_telemetry.cpp` 的 JSON 組字串緩衝區(`live_buf[2048]`、`curve_buf[6144]`)刻意宣告成**檔案層級的 `static`**，不是函式內區域變數：
  - 若宣告成區域變數(放在任務堆疊上)，`curve_buf` 一個就要 6KB，而該任務堆疊只給 6144 bytes，會直接把整個堆疊吃光，甚至溢位到隔壁記憶體(FreeRTOS 堆疊溢位是韌體最常見的隨機當機／飛車成因之一)。
  - 改成 `static` 後，這兩塊緩衝區落在 `.bss` 區段，大小在**編譯期**就固定、生命週期等於整個程式執行期，不會有「用到才配置、配置失敗」的問題，也不會被任何其他任務誤用(因為是各自檔案內的 `static`，連結時對其他編譯單元不可見)。
  - `append()` 輔助函式每次呼叫都用「剩餘容量」夾住 `vsnprintf`，任何情況都不會寫出陣列邊界；一旦被截斷(`len` 會被夾到等於 `buf_size`)，後續 `append()` 呼叫會因為 `len>=buf_size` 直接跳過，不會用負數/溢位長度去算位置。
- `measure_settings` 結構體裡的陣列(`res_point_*[RES_MAX_POINTS]`、`curve_*[MAX_CURVE_POINTS]`)全部是結構體內的**固定大小陣列**，隨結構體一起以 `volatile measure_settings meas_settings{};` 的方式在 `measure_seq.cpp` 靜態配置，不是指標＋動態配置。所有存取函式(`meas_res_get/set_point`、`meas_curve_get/set_point`)都先檢查 `idx >= 上限` 才動作，越界存取會直接回傳 `false`、不會寫壞記憶體。

### 1.2 陣列容量與實際使用量

| 陣列 | 容量 | 單筆大小 | 總大小 | 實際會用到 |
|---|---|---|---|---|
| `res_point_rpm/rth/ke` | `RES_MAX_POINTS`=3 | 3×float=12B | 36B | 固定 3 點(低/中/高) |
| `curve_rpm/v_at_maxp/p_max/r_opt` | `MAX_CURVE_POINTS`=180 | 4×float=16B | 2880B | 依 `n_lim` 而定，通常遠小於 180 |

`MAX_CURVE_POINTS=180` 是刻意抓到「就算 `n_lim` 逼近 `RPM_RUNAWAY_MAX`(17000)、起點抓最低 1000 附近、每 100RPM 一點」都還有餘裕的容量((17000-1000)/100=160 < 180)，`curve_calc_run()` 裡的 `for` 迴圈本身也用 `count < MAX_CURVE_POINTS` 再上一道保險，兩層保護不會寫出陣列。

### 1.3 實際編譯結果(PlatformIO，`pio run`，2026-08-27)

```
RAM:   17.5% (used 57500 bytes from 327680 bytes)
Flash: 90.1% (used 1181311 bytes from 1310720 bytes)
```

- **RAM 非常寬裕**(剩餘約 270KB)，新增的所有共享結構＋緩衝區＋6 個任務堆疊(見 1.4)全部算進去只佔整體 17.5%，沒有 RAM 不足風險。
- **Flash 只剩約 129KB(9.9%)餘裕**，這是本次新增後才浮現的真實限制，主因是 `U8g2`(內建幾百種面板驅動，即使只用到 SSD1306/SH1106 兩種)與 `BluetoothSerial`(完整 Bluedroid classic 協定疊)本身就很佔空間。**目前這個容量還能正常燒錄執行**(已實測)，但若之後還要繼續加功能，建議：
  1. 把 `platformio.ini` 的 `board_build.partitions` 換成 `huge_app.csv` 或自訂分割表，把 OTA/次要 app 分割區讓給主程式(4MB flash 通常還能再擠出幾百 KB)。
  2. 或改用 `U8x8`(純文字模式，不含圖形/大量字型)取代 `U8g2`，可省下可觀的 Flash，但目前的圖形化 OLED 畫面需要小幅改寫。
  3 本次**沒有**做這兩項優化，因為目前仍在可燒錄範圍內、不屬於「會不會死機/飛車」的安全性問題，屬於之後功能擴充前才需要處理的空間規劃。

### 1.4 六個 FreeRTOS 任務的堆疊配置

| 任務 | 核心 | 優先權 | 堆疊 | 內部有無大型區域變數 |
|---|---|---|---|---|
| `motor_PID`(既有) | 0 | 16 | 6144 | 無(本次未改動大小) |
| `speed_sensor`(既有) | 0 | 15 | 4096 | 無(本次未改動大小) |
| `ina232`(既有) | 0 | 4 | 4096 | 無 |
| `board_ui`(既有) | 1 | 8 | 6144 | 無 |
| **`measure_seq`(新增)** | 1 | 3 | 4096 | 無(`safe_current_step`/`gen_resistance_step` 內都只有幾個 `float`/`bool` 區域變數) |
| **`bt_telemetry`(新增)** | 1 | 2 | 6144 | 無(2KB/6KB 緩衝區皆為 `static`，不占堆疊) |

新增兩個任務都放在 **Core 1**、優先權刻意低於 `board_ui`(8)、高於 Arduino `loop()`(預設 1)，不會搶佔 Core 0 上 `motor_PID`(16)／`speed_sensor`(15) 的即時控制路徑，符合既有的「量測/顯示類任務不干擾控制迴路」設計原則(`ina232` 當初也是同樣考量放到低優先權)。

---

## 2. 鎖與資料競爭分析

### 2.1 現有 6 把自旋鎖

| 鎖 | 保護的結構 | 唯一寫入者(任務) |
|---|---|---|
| `g_speed_mux`(既有) | `settings`(speed_sensor) | `speed_sensor` 任務為主，`motor_PID`/`main`/新模組的 `fail_hard()`/`speed_trigger_fault()` 在觸發故障時也會寫 |
| `g_pid_mux`(既有) | `PID_settings` | `motor_PID` 任務；`measure_seq`/`safe_current`/`gen_resistance` 只會呼叫 `pid_set_keep_rpm()` 這一個外部入口 |
| `g_ina_mux`(既有) | `ina_settings` | `ina232` 任務 |
| `g_ui_mux`(既有) | `ui_settings` | `main`(Arduino `loop()`) |
| **`g_meas_mux`(新增)** | `measure_settings` | **只有 `measure_seq` 任務**(內含呼叫 `safe_current_step()`/`gen_resistance_step()`/`curve_calc_run()`，這 3 個函式都是被 `measure_seq` 同一個任務「呼叫」執行，不是獨立任務) |
| **`g_bt_mux`(新增)** | `bt_telemetry_state` | **只有 `bt_telemetry` 任務** |

`fault` 相關欄位(`settings.fault`/`fault_code`/...)雖然本來就有 3 個既有寫入點(`motor_PID.cpp`、`speed_sensor.cpp` 各自的 `trip_fault()`，加上 `main.cpp` 的 `trigger_estop()`)，本次新增了第 4 個寫入點：`settings.h` 新增的共用函式 `speed_trigger_fault()`，供 `safe_current.cpp`/`gen_resistance.cpp` 的 `fail_hard()` 呼叫。**四個寫入點各自完整地用同一把 `g_speed_mux`、寫入同一組欄位、寫入內容彼此一致(都是「故障鎖定」這個事實的完整快照)**，不會因為「這次是誰觸發的」而出現欄位互相矛盾的中間狀態。這是刻意的設計：**新模組重用既有、已經過審視的鎖定機制，而不是自己發明一套平行的安全鎖定路徑**。

### 2.2 逐一確認：新增程式碼從未同時持有兩把鎖

這是本次覆查最重要的一項，因為「巢狀持有不同鎖」是死結(deadlock)最典型的成因。逐檔案追蹤如下(每個函式呼叫都是「進入→做完→返回」，不會把鎖跨函式呼叫帶著走)：

- **`measure_seq.cpp`**：
  - `enter_pause()`：`meas_set_resume_phase()`(鎖/解鎖) → `meas_set_pause_request()`(鎖/解鎖) → `load_switch_set()`(內部呼叫 `meas_set_load_connected()`，鎖/解鎖) → 一個獨立的 `SettingsLockGuard(g_meas_mux)` 區塊只寫 `link_lost`/`phase` 兩個欄位。全部依序執行，沒有任何一步在鎖還沒放開前又去呼叫別的加鎖函式。
  - `handle_link_lost_state()`：同樣模式，`wait_for_resume_stable()` 迴圈裡只呼叫 `speed_get_fault()`/`speed_get_speed_stable()`(各自獨立鎖 `g_speed_mux`)，且這段迴圈**完全沒有持有 `g_meas_mux`**(呼叫這個函式前後才各自獨立加解鎖)。
  - `measure_seq_task()` 主迴圈：`speed_get_fault()`、`meas_get_phase()`、`check_generator_link()`(內部只呼叫 `speed_get_speed_stable()`/`ina_get_online()`/`ina_get_data_valid()`/`ina_get_bus_V()`，全部獨立鎖)、以及呼叫 `safe_current_step()`/`gen_resistance_step()`/`curve_calc_run()`——這些呼叫「當下」都沒有持有 `g_meas_mux`。
- **`safe_current.cpp`**：每個 `case` 分支都是「呼叫若干個 `meas_get_x()`/`ina_get_x()`/`speed_get_x()`(各自獨立鎖) → 算一算 → 呼叫 `meas_set_x()`/`goto_phase()`(各自獨立鎖)」，`finish_with_result()`/`fail_hard()` 內部的 `SettingsLockGuard` 區塊都只包住「純欄位賦值」，不在區塊內呼叫任何其他加鎖函式。
- **`gen_resistance.cpp`**：與上面同一種模式，`finish_averaging()` 的迴圈(呼叫 `meas_res_get_point()`，各自獨立鎖)在迴圈外面、跟後面「寫入平均值」的 `SettingsLockGuard(g_meas_mux)` 區塊是兩個獨立、不重疊的臨界區。
- **`curve_calc.cpp`**：讀值(`meas_get_res_rth_ohm()` 等)、寫入中繼結果(一個 `SettingsLockGuard(g_meas_mux)` 區塊)、逐點計算迴圈裡呼叫 `meas_curve_set_point()`(各自獨立鎖)，同樣沒有巢狀。
- **`bt_telemetry.cpp`**：`build_live_message()`/`build_curve_message()` 呼叫的每一個 `xxx_get_y()` 都是獨立的一次鎖/解鎖，兩個函式之間也不會互相巢狀呼叫。

**結論：新增程式碼的鎖使用完全符合既有規範「同一時間只持有一顆鎖」，不存在巢狀持鎖，因此不可能因為鎖的順序不同而死結。**

### 2.3 多欄位一致性(避免「新A配舊B」)

凡是「好幾個欄位代表同一件事實、必須一起看才有意義」的地方，都用 `SettingsLockGuard` 包住整段直接寫欄位，而不是呼叫多次獨立的 `set_x()`(那樣中間會有其他任務讀到「一半新一半舊」的風險)。本次新增程式碼中這樣處理的地方：

- `safe_current.cpp::finish_with_result()`：`safe_i_cont_A`＋`safe_i_cont_rpm`＋`safe_done` 三個欄位一起寫。
- `safe_current.cpp` 判定通過時：`safe_pass_any`＋`safe_last_pass_rpm`＋`safe_last_pass_A` 三個欄位一起寫。
- `gen_resistance.cpp::gen_resistance_reset()`／`finish_averaging()`：重置/寫入結果時，相關欄位都在同一個鎖區塊內。
- `curve_calc.cpp`：`curve_n_rl`/`n_knee`/`n_voc`/`n_lim`/`curve_limit_reason` 五個欄位一起寫，讀取端(`bt_telemetry`／OLED)不會看到「`n_lim` 已更新但 `curve_limit_reason` 還是舊的」這種組合。
- `measure_seq.cpp::enter_pause()`：`link_lost`＋`phase` 一起寫。

---

## 3. 時間軸／狀態機分析

### 3.1 暫停(發電機斷線)→ 續測 的完整時序驗證

這是本次最容易出錯、也是我在實作前就先驗證過的一段(過程見對話紀錄)，這裡摘要成可檢核的時間軸：

1. `measure_seq` 偵測到 `bus_V` 連續 `GEN_LINK_LOST_TIMEOUT_MS` 低於門檻 → 呼叫 `enter_pause()`：`pause_request=true`、負載斷開、`phase=MEAS_LINK_LOST`。
2. **同一瞬間**，`motor_PID` 任務下一次被喚醒(最多等 `read_space`≈15ms)時，第一個 `if(speed_get_fault())` 為 false，接著新增的 `if(meas_get_pause_request())` 為 true → PWM 立刻歸零、`init_phase=SPEED_PHASE_PID_PAUSED`、**刻意不清 `const_speed_ready`／`autotune_done`**。
3. 馬達實際轉速歸零後，`speed_sensor` 既有的「真停轉」偵測(`SPEED_STALL_TIMEOUT_MS`=300ms 無新脈衝)會自然把 `const_speed_ready` 置 false──**這一步我特別修改了 `speed_sensor.cpp::update_phase_after_sample()`**，讓它同時認得 `SPEED_PHASE_PID_PAUSED`(比照原本就有特殊處理的 `PID_TUNE`/`PID_RUN`)，否則這個既有函式會在暫停期間每輪把 `init_phase` 搶回 `READY`、把 `const_speed_ready` 搶回 `true`，兩個任務對同一組欄位「互踩」，畫面會每 15ms 閃爍一次(已在實作中發現並修正，見 `speed_sensor.cpp` 的修改註解)。這個閃爍**不影響安全**(因為 `motor_PID` 的暫停判斷只看 `pause_request`，不看 `const_speed_ready`)，但會誤導顯示，所以已經修正。
4. 使用者排除斷線、按下 START：`main.cpp` 偵測到 `ui_state==UI_LINK_LOST` 時的按鈕邊緣 → 呼叫 `resume_after_link_loss()`：只做 `meas_set_resume_requested(true)` 與樂觀地把 `ui_state` 設回 `UI_RUNNING`。
5. `measure_seq` 任務下一輪迴圈看到 `resume_requested` → 清掉它、把 `pause_request` 設回 false、重置斷線監測的「已穩過一次」旗標(`reset_link_monitor()`，避免把「還沒重新穩定前的低電壓」誤判成又斷線一次)。
6. `motor_PID` 看到 `pause_request` 變 false，加上 `const_speed_ready` 這時多半也已經是 false(因為第 3 步的真停轉偵測)，於是走既有的「測速尚未完成」分支呼叫 `open_loop_step_control()`——**因為 `ol_hold` 與 `step_pwm`(本地靜態變數)全程沒被清除**，這個既有函式的第一個判斷式 `if (speed_get_ol_hold())` 會直接重新套用「上次已知可行」的 PWM，不必重新從最低階爬升。
7. 轉速回升、`speed_sensor` 量到新的同位置整圈資料 → 因為 `settle_samples_local` 也全程沒被歸零，`const_speed_ready` 幾乎立刻(下一筆有效樣本)重新變 true。
8. `motor_PID` 的 `!pid_get_autotune_done()` 為 false(因為 `autotune_done` 全程沒被暫停邏輯動過)，直接跳過整段自動調參，進入「PID 定速」，用暫停前就已經算好的 `Kp`/`Ki`/`Kd` 把轉速拉回 `keep_rpm`(這是本次開機自動調參後系統自然停下來的轉速，同樣全程沒被暫停邏輯動過──**不是**任何寫死的常數，見下方 2026-08-27 修訂記錄)。
9. `measure_seq::wait_for_resume_stable()` 等到 `speed_get_speed_stable()` 變 true(有逾時保護 `SAFE_SPEED_WAIT_TIMEOUT_MS`)，才呼叫「目前模組」的 `_reset()`(整段重來)並把 `phase` 設回該模組，重新開始量測。

**這段時序的關鍵安全性質**：從第 1 步到第 9 步，`speed_get_fault()`／既有的飛車保護／既有的無脈衝看門狗**全程持續有效**(它們檢查的是 `now_speed`/`ol_pwm_cmd` 等欄位，跟本次新增的暫停邏輯用的是完全不同的欄位與判斷路徑，兩者是「疊加」關係，不是「取代」關係)。就算暫停/恢復的邏輯本身有沒想到的漏洞，既有這兩道防線仍然會在轉速異常或馬達卡死時獨立動作。

### 3.2 量測序列三模組交接的一致性

`measure_seq` 是**唯一**呼叫 `safe_current_step()`/`gen_resistance_step()`/`curve_calc_run()` 的地方，而且是**同一個任務、依序**呼叫(不會同時呼叫兩個)，所以三個模組之間不需要額外的鎖來保護「交接」──`meas_settings.phase` 這一個欄位本身就是交接的協議：`measure_seq` 只有在確認 `safe_current_step()`/`gen_resistance_step()` 回傳 `true`**且 `speed_get_fault()` 仍為 false**(這是我在整合時額外加的守門判斷，見下方 3.3)才會把 `phase` 切到下一個模組；下一個模組的 `_reset()`／`_step()` 從呼叫的那一刻才開始執行，不會有「還在跑安全電流，內阻卻已經開始改變目標轉速」這種交叉執行的情況。

### 3.3 「硬故障但函式仍回傳 true」的收尾陷阱(已修正)

`safe_current_step()`/`gen_resistance_step()` 在呼叫 `fail_hard()`(觸發整機安全鎖定)的分支裡也回傳 `true`，語意是「本模組的狀態機已經跑完，不用再呼叫我了」──但 `measure_seq` 原本若只看「回傳 true 就進下一階段」，會在**硬故障當下**還誤把 `phase` 推進到 `MEAS_RESISTANCE`/`MEAS_CURVE_CALC`。這在實作時已經發現並修正：`measure_seq.cpp` 在兩個轉階段的地方都先檢查 `if (speed_get_fault()) { break; }` 才真正切換 `phase`。硬故障發生時，`phase` 會停在原地，下一輪迴圈最上方的 `if (speed_get_fault()) continue;` 會接手，整個任務之後只做「什麼都不做地空轉」，等待重開機。

### 3.4 內阻模組單點失效 vs. 全部失效

`gen_resistance.cpp::RES_PH_COMPUTE` 對算出來不合理的 `R_th`(負值/太大/太小/非有限數)採取「丟棄這一點、繼續下一點」而不是立刻整機鎖定，只有 `finish_averaging()` 發現**三點全部失效**時才會 `fail_hard()`。這是刻意設計：單一取樣點偶發雜訊(換向瞬間、INA 抖動)不應該讓已經跑了很久的安全電流+內阻識別直接報廢重來；但如果連一個有效點都拿不到，代表接線或方法本身有問題，不應該用「猜」的數字去算後面的曲線，因此才整機鎖定。

---

## 4. 既有安全機制保留確認

逐一核對本次修改是否影響三道既有防線：

| 既有機制 | 檢查點 | 是否被本次修改影響 |
|---|---|---|
| **RPM 飛車保護**(`RPM_RUNAWAY_MAX`) | `speed_sensor.cpp::runaway_protect()`、`motor_PID.cpp` 閉環段、sTune 調參段 | **完全未修改**這三處判斷式本身；新增的 `SAFE_RPM_MAX_CEILING`(預設 6000RPM)是量測序列**自己額外疊加**的、更保守的人為上限，不會、也不能讓系統跑到比既有 17000RPM 更高 |
| **馬達通電看門狗**(`NO_PULSE_TIMEOUT_MS`) | `speed_sensor.cpp::runaway_protect()` | **完全未修改**判斷式；本次新增的暫停邏輯會主動把 `ol_pwm_cmd` 設回 0，讓這個看門狗在暫停期間正確地「不判定為卡死」(這本來就是看門狗設計的本意：命令停止就不該被當成異常) |
| **ESTOP(板上 START 鈕)** | `main.cpp::trigger_estop()` | **完全未修改**；新增的 `UI_LINK_LOST` 是與 `UI_ESTOP` 平行的新狀態，兩者用不同旗標(`link_lost`/`pause_request` vs `fault`)驅動，互不干擾。使用者在 `UI_RUNNING` 按 START 仍然是 ESTOP，在 `UI_LINK_LOST` 按 START 才是「請求恢復」，語意上不會混淆(且恢復流程本身也會受既有 `speed_get_fault()` 檢查把關，見 3.1 第 9 步) |
| **開環起動階梯／sTune 自動調參** | `motor_PID.cpp` | 開環爬升與調參邏輯**逐行未動**；曾經加過一行 `pid_set_keep_rpm(MEASURE_MIN_RPM)` 想讓每次開機的定速目標是確定的常數，但這會讓系統在調參完成瞬間被命令跳去一個沒被特性化過的工作點，實測長時間震盪不收斂，已於 2026-08-27 移除，改回原始的「keep_rpm 鎖存自然停下來的轉速」邏輯，見下方修訂記錄 |

---

## 5. 新增的失效模式與因應方式

| 情境 | 偵測方式 | 因應 |
|---|---|---|
| 發電機鱷魚夾脫落(電壓歸零) | `bus_V` 連續 `GEN_LINK_LOST_TIMEOUT_MS` 低於 `GEN_LINK_LOST_V_MAX` | 非故障暫停(`UI_LINK_LOST`)，重按 START 整段重跑目前模組 |
| INA232 中途離線 | 各模組每個關鍵步驟都檢查 `ina_get_online() && ina_get_data_valid()` | 視同硬故障，`fail_hard()` 整機鎖定(量測期間沒有電流回饋等於沒有安全網，不可以繼續帶載) |
| 負載開關卡死(斷開時仍量到電流) | 開路取樣步驟檢查 `oc_a > SAFE_OC_MAX_CURRENT_A` | `fail_hard()` 整機鎖定 |
| 帶載後電流過小(接觸不良/沒接上) | 檢查 `< SAFE_I_MIN_VALID_A` / `RES_MIN_VALID_A` | `fail_hard()` 整機鎖定 |
| 任何時刻電流超過硬天花板 | 每個等待迴圈都即時檢查 `SAFE_I_HARD_CEILING_A`，不是只在取樣瞬間檢查 | 立即斷負載＋`fail_hard()` |
| 安全電流第一檔就不通過 | `safe_pass_any==false` 時判定不通過 | 無法給出任何安全電流，`fail_hard()`(不會硬套用一個不安全的數字) |
| 內阻三點全部無效 | `finish_averaging()` 的 `counted==0` | `fail_hard()`(不會用無效數字算曲線) |
| 曲線計算輸入無效(理論上不會發生) | `curve_calc_run()` 開頭檢查 `rth>0 && ke>0` | 寫入空結果(`curve_point_count=0`)並印訊息，防禦性寫法，不會用垃圾數字硬算 |
| 等待穩調逾時(轉速一直拉不上去) | `SAFE_SPEED_WAIT_TIMEOUT_MS`/`RES_SPEED_WAIT_TIMEOUT_MS` | `fail_hard()` |
| 安全電流階梯撞到 `SAFE_RPM_MAX_CEILING` | 已通過至少一檔 → 用該檔收尾；一檔都沒過 → `fail_hard()`(代表天花板設太低，需要調常數) |

---

## 6. 已知限制／需要依實際機台調整的常數

以下常數已在 `settings.h` 內逐一加註「★依實際機台調整」，這裡集中列出，實際上機前務必檢視：

- `SAFE_I_HARD_CEILING_A`(預設 0.6A，須低於 INA232 0.8A 滿量程)
- `SAFE_RPM_STEP`(預設 300RPM)、`SAFE_RPM_MAX_CEILING`(預設 6000RPM，務必遠低於 `RPM_RUNAWAY_MAX`=17000)
- `SAFE_COOLDOWN_MS`(預設 30 秒，依實際散熱調整)
- `GEN_LINK_LOST_V_MAX`(預設 0.15V，須遠小於最低轉速下的開路電壓)
- `CURVE_V_ALLOW`(預設 40V，須低於 INA232 與後級真正的耐壓)
- `LOAD_TEST_RESISTOR_OHM`(預設 20Ω，需與實際外接電阻一致；改了必須同步更新，程式本身不會自動偵測外接電阻的實際阻值)

另外兩個**設計上的簡化**，不是缺陷，但要知道：

- 本次**沒有**把安全電流/內阻/曲線的結果存進 NVS(Flash)。每次重開機都會整段重新量測。這是因為使用情境是「每次都重新裝上一顆待測發電機」，不是「量一次、之後開機沿用」；若之後需要跨開機沿用，`ARCH.md` 文件裡有預留這個彈性設定的位置，但目前程式碼還沒實作。
- 內阻模組的三個轉速點(高/中/低)是**由安全電流階梯的結果反推**(`I_cont` 對應的最高通過檔、與起始轉速的中點、起始轉速)，**量測順序為高→中→低**(避免安全電流結束後立刻大幅降速逾時)；如果之後想要指定別的轉速點策略，要改 `gen_resistance.cpp::target_rpm_for_point()`。

---

## 7. 建構驗證紀錄

```
$ pio run
...
Compiling .pio/build/mhetesp32devkit/src/measure_seq/measure_seq.cpp.o
Compiling .pio/build/mhetesp32devkit/src/safe_current/safe_current.cpp.o
Compiling .pio/build/mhetesp32devkit/src/gen_resistance/gen_resistance.cpp.o
Compiling .pio/build/mhetesp32devkit/src/curve_calc/curve_calc.cpp.o
Compiling .pio/build/mhetesp32devkit/src/bt_telemetry/bt_telemetry.cpp.o
...
RAM:   [==        ]  17.5% (used 57500 bytes from 327680 bytes)
Flash: [========= ]  90.1% (used 1181311 bytes from 1310720 bytes)
========================= [SUCCESS] Took 35.58 seconds =========================
```

唯一的編譯警告是 `BluetoothSerial` 本身標了 `[[deprecated]]`(官方預告未來版本可能預設拿掉 classic BT 支援)，不影響本次功能，純粹是上游函式庫的長期规划提示。

---

## 8. 建議的上機測試順序(對應各 ARCH.md 文件的「建議實作順序」，這裡是整合後的版本)

1. **先不接發電機負載**，只確認 `SERVO_PIN` 的電位方向對(高電位量到通/斷是否符合 `LOAD_SWITCH_ACTIVE_HIGH` 的預期)。
2. 確認開環爬升＋自動調參本身能正常收斂到穩定閉環(這部分邏輯完全沿用既有、已經跑得動的開環+調參+閉環，未被本次改動觸碰)，且 `speed_stable` 會在合理時間內變 true。
3. 把 `SAFE_THERMAL_SOAK_MAX_MS`／`SAFE_THERMAL_CHECK_WINDOW_MS` 暫時改成幾十秒(乾跑)，確認整個 `MIN_SPEED_HOLD → SAFE_CURRENT → RESISTANCE → CURVE_CALC → DONE` 的階段真的會依序推進，序列埠(`[MEAS]`/`[SAFE_I]`/`[RES]`/`[CURVE]` 開頭的訊息)可以逐行對照。
4. 用真實電阻接上，跑一次完整(分鐘級)識別，核對 `[SAFE_I]`/`[RES]` 印出的每檔/每點數字是否合理。
5. 手動把鱷魚夾拔掉，確認 3 秒後進入 `UI_LINK_LOST`(OLED 顯示變化、序列埠印 `[MEAS] generator link lost...`)，接回並按 START，確認會重新爬升並整段重跑「當時正在跑的那個模組」。
6. 最後才連藍牙，用序列埠工具(或先用手機藍牙序列 App)確認每 200ms 收到一行 `{"t":"live",...}`，`curve_done` 之後每 3 秒收到一行 `{"t":"curve",...}`，再進上位機端的開發。

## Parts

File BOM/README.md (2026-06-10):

## BOM

點擊此資料夾內的ibom.html檔案可開啟互動式BOM表單(使用KiCad的Interactive HTML BOM插件製作)，點選電路板上的元件時表單上的項目會高亮指示，反之亦然。另外也有提供Excel格式的BOM表單<br><br>
[回到主頁](../README.md)

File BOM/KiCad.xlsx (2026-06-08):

Reference | Qty | Value | DNP | Exclude from BOM | Exclude from Board | Footprint | Datasheet
C1,C7,C8,C10,C12 | 5 | 1uF |  |  |  | Capacitor_SMD:C_0603_1608Metric | ~
C2,C14 | 2 | 22uF |  |  |  | Capacitor_SMD:C_0805_2012Metric | ~
C3 | 1 | 150pF |  |  |  | Capacitor_SMD:C_0603_1608Metric | ~
C4,C5,C6,C9,C11,C13,C15,C16,C17,C18 | 10 | 0.1uF |  |  |  | Capacitor_SMD:C_0603_1608Metric | ~
D1,D3 | 2 | B340 |  |  |  | Diode_SMD:D_SMC | http://www.jameco.com/Jameco/Products/ProdDS/1538777.pdf
D2 | 1 | SS14 |  |  |  | Diode_SMD:D_SMA | https://www.vishay.com/docs/88746/ss12.pdf
J1 | 1 | DC-IN |  |  |  | Connector_BarrelJack:BarrelJack_Kycon_KLDX-0202-xC_Horizontal | ~
J2 | 1 | TYPE-C |  |  |  | USB4105-GF-A:GCT_USB4105-GF-A
J3,J4,J5,J6 | 4 | Conn_01x03_Pin |  |  |  | Connector_PinHeader_2.54mm:PinHeader_1x03_P2.54mm_Vertical | ~
L1 | 1 | 15uH |  |  |  | DC-DC POWER L1:WE-PD_1260
Q1 | 1 | IRF3708 |  |  |  | IRF3708:TO-220-3_L10.0-W4.6-P2.54-L
R1 | 1 | 210K |  |  |  | Resistor_SMD:R_0603_1608Metric | ~
R2 | 1 | 40.2K |  |  |  | Resistor_SMD:R_0603_1608Metric | ~
R3 | 1 | 100K |  |  |  | Resistor_SMD:R_0603_1608Metric | ~
R4 | 1 | 200K |  |  |  | Resistor_SMD:R_0603_1608Metric | ~
R5,R6,R7 | 3 | 5.1K |  |  |  | Resistor_SMD:R_0603_1608Metric | ~
R8 | 1 | 0.1R |  |  |  | Resistor_SMD:R_2512_6332Metric | ~
R9,R10,R11 | 3 | 10K |  |  |  | Resistor_SMD:R_0603_1608Metric | ~
SW1 | 1 | reset |  |  |  | button:SW-TH_4P-L6.0-W6.0-P4.50-LS6.5 | https://lcsc.com/product-detail/Tactile-Switches_SHOU-HAN-TS665CJ_C393938.html
SW2 | 1 | start |  |  |  | button:SW-TH_4P-L6.0-W6.0-P4.50-LS6.5 | https://lcsc.com/product-detail/Tactile-Switches_SHOU-HAN-TS665CJ_C393938.html
U1 | 1 | ESP32-WROOM-32E |  |  |  | RF_Module:ESP32-WROOM-32D | https://www.espressif.com/sites/default/files/documentation/esp32-wroom-32e_esp32-wroom-32ue_datasheet_en.pdf
U2 | 1 | MP1584EN |  |  |  | MP1584:SOIC127P600X170-9N
U3 | 1 | CH340C |  |  |  | Package_SO:SOIC-16_3.9x9.9mm_P1.27mm | https://datasheet.lcsc.com/szlcsc/Jiangsu-Qin-Heng-CH340C_C84681.pdf
U4 | 1 | RT9013-33GB |  |  |  | RT9013-33GB:SOT94P279X129-5N
U5 | 1 | DM-OLED096-636 |  |  |  | OLED:MODULE_DM-OLED096-636
U6 | 1 | INA232AIDDFR |  |  |  | INA232AIDDFR:SOT65P280X110-8N
U7 | 1 | MIC4420YM |  |  |  | MIC4420YM:SOIC-8_L4.9-W3.9-P1.27-LS6.0-BL
U8 | 1 | LM358 |  |  |  | Package_SO:SOIC-8_5.3x6.2mm_P1.27mm | http://www.ti.com/lit/ds/symlink/lm2904-n.pdf

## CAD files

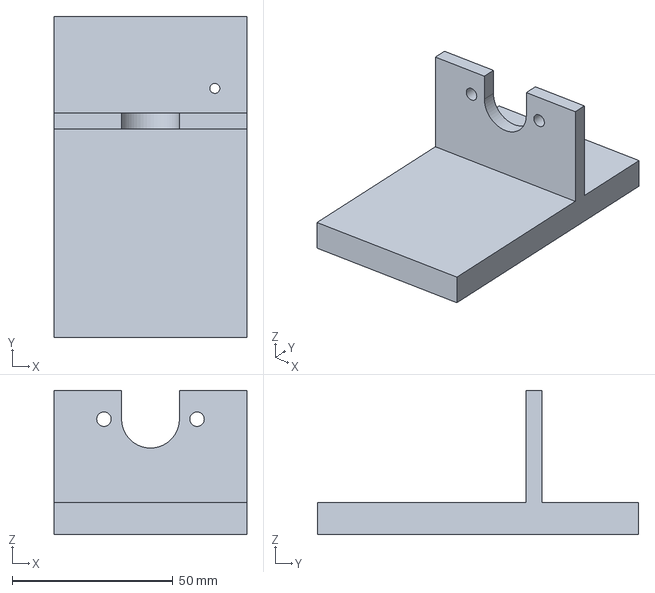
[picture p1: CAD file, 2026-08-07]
3D_print_Component/ESP32_MPPT.FCStd
60.0 x 100.0 x 45.0 mm

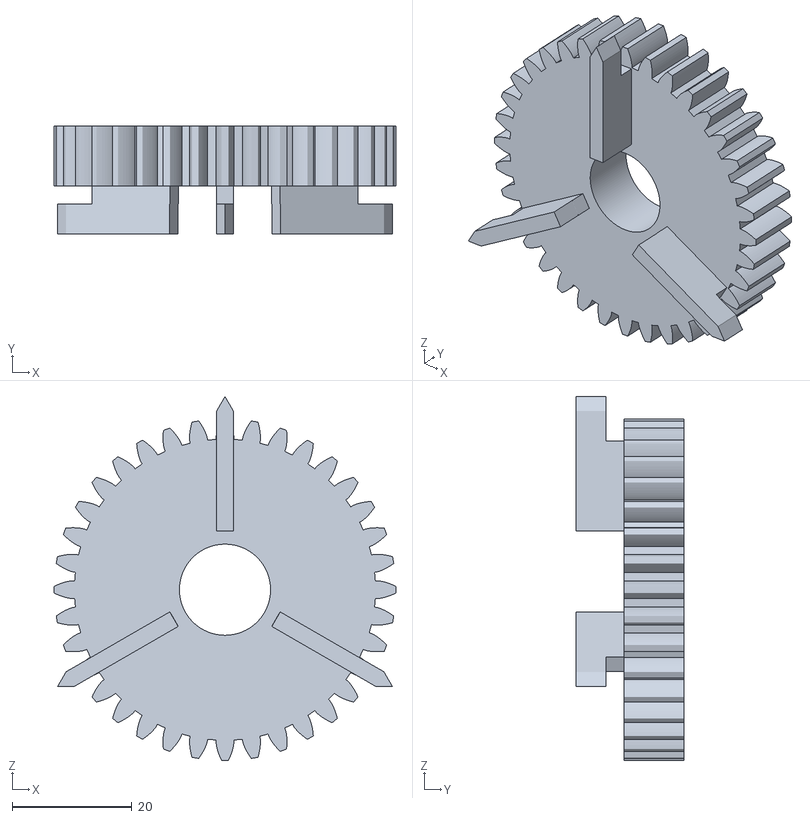
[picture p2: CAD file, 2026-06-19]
3D_print_Component/STL/1_X/1_5.stl
57.0 x 18.0 x 60.7

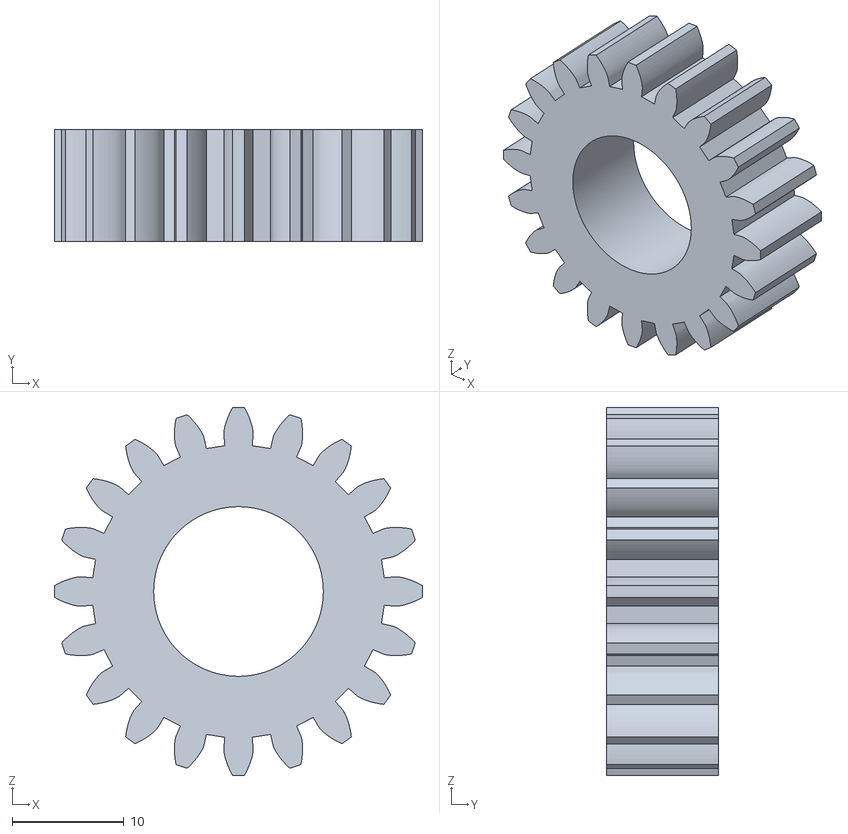
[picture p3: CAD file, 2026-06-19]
3D_print_Component/STL/1_X/1_0-1.stl
33.0 x 10.0 x 33.0

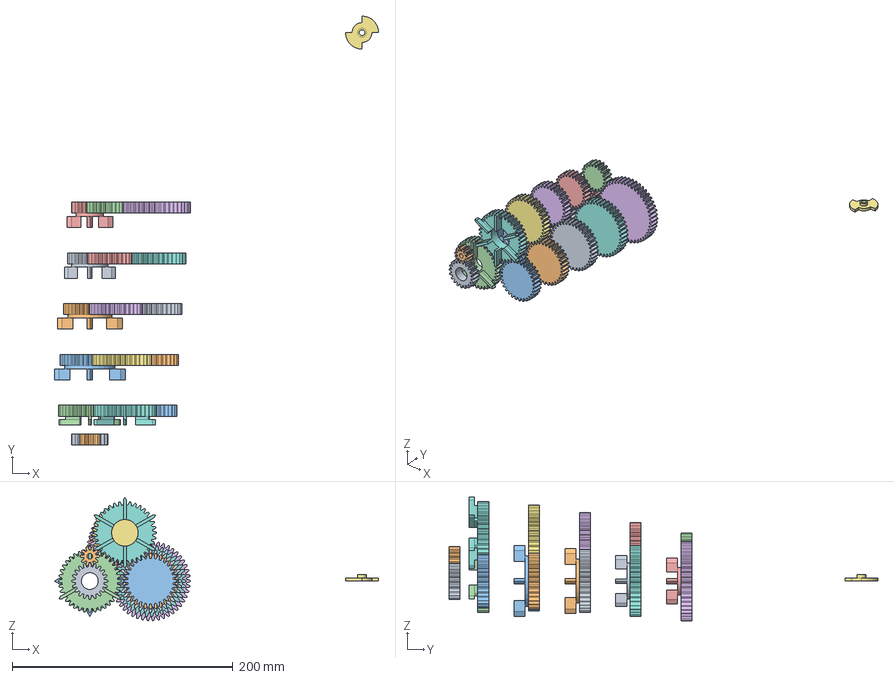
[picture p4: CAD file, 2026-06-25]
3D_print_Component/ESP32_MPPT_TEST.FCStd
293.6 x 388.5 x 111.9 mm
speed_sensor
1_0-M

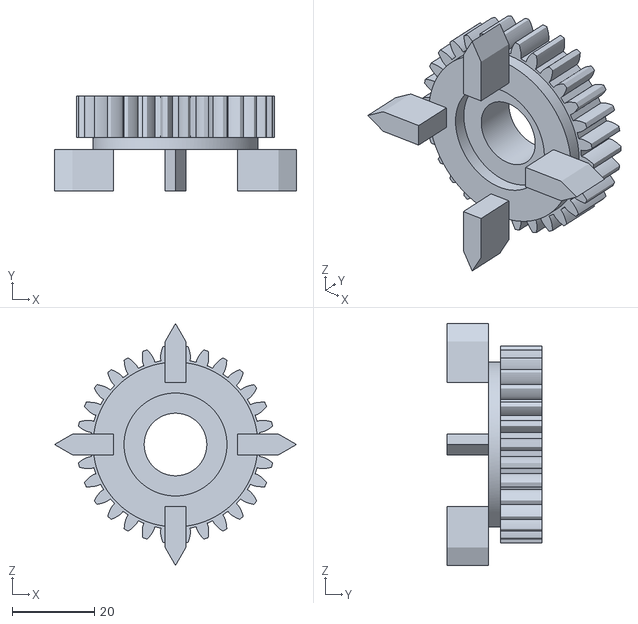
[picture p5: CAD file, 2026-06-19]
3D_print_Component/STL/1_X/1_3.stl
58.8 x 23.0 x 58.8

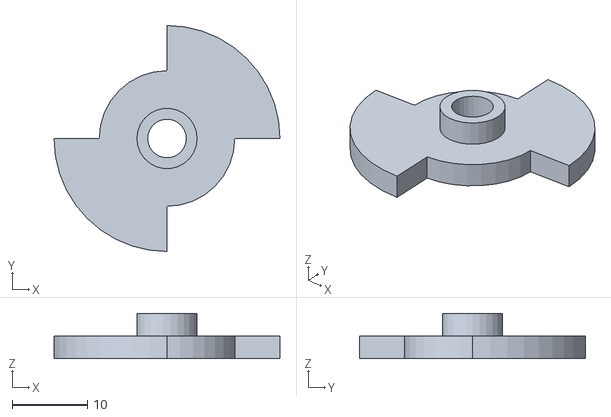
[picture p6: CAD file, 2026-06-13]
3D_print_Component/ESP32_MPPT_TEST-主體.stl
30.0 x 30.0 x 6.00

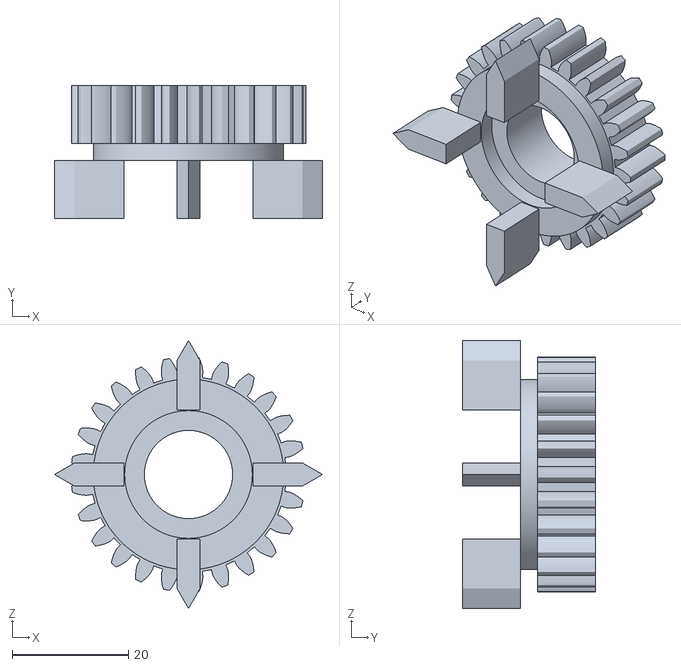
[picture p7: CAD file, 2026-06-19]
3D_print_Component/STL/1_X/1_2.stl
46.2 x 23.0 x 46.2

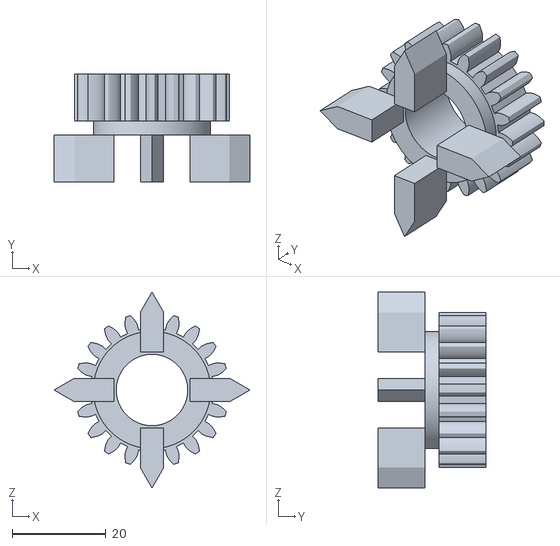
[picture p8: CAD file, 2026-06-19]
3D_print_Component/STL/1_X/1_1.stl
41.8 x 23.0 x 41.8

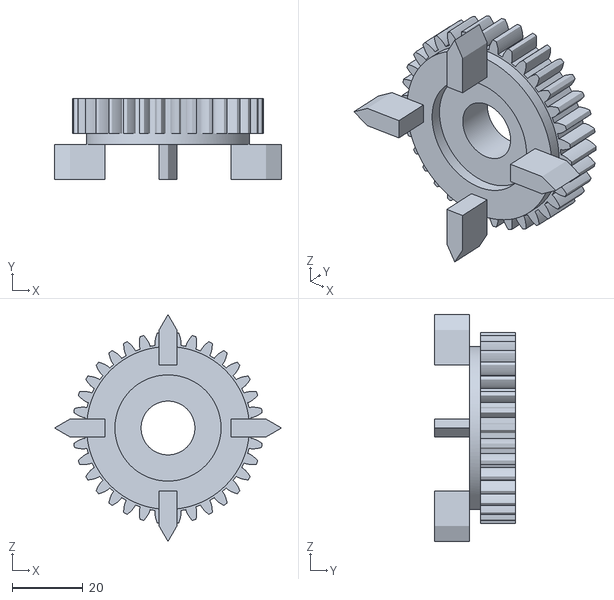
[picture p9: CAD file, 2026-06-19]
3D_print_Component/STL/1_X/1_4.stl
64.2 x 23.0 x 64.2

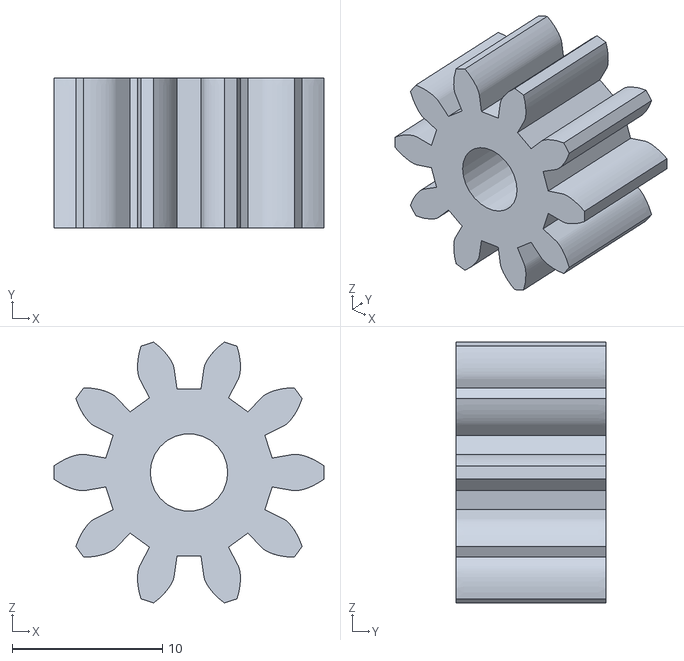
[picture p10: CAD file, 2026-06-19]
3D_print_Component/STL/1_X/1_0-M.stl
18.0 x 10.0 x 17.4

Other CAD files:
3D_print_Component/ESP32_MPPT-主體.stl

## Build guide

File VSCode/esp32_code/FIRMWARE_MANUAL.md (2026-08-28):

# ESP32 Micro-Generator 韌體說明書（完整版）

> 適用路徑：`VSCode/esp32_code/`  
> 平台：PlatformIO + Arduino-ESP32（底層 ESP-IDF 5.5.x）  
> 目的：讀完本文件應能完整理解「系統在做什麼、各模組如何協作、保護如何觸發、參數要改哪裡」。

---

## 0. 這台機器在幹嘛？

本專案是以 **ESP32** 為核心的 **微型發電機 / MPPT 量測平台**：

1. 用有刷直流馬達當 **主動力馬達**（PWM 驅動，目標是把轉速穩在某 RPM）。
2. 另一側（或同一系統）量測發電側電氣參數（INA232：電壓／電流／功率）。
3. 先把主動力馬達 **定速**，再去做功率曲線／MPPT 相關量測（MPPT 算法本身仍在發展中）。

韌體目前已完成的核心是：

- 光柵測速（MCPWM Capture）
- 階梯開環起動 → 就緒觀察 → sTune 自動調 PID → 閉環定速
- 飛車／無脈衝看門狗／急停等保護
- OLED 顯示 + START 鈕起動／急停
- INA232 電氣量測

---

## 1. 倉庫與檔案架構

```
micro generator/
├── README.md                          # 專案總覽（硬體/結構）
├── KiCad/                             # 原理圖、PCB
├── BOM/
├── 3D_print_Component/                # 光柵等 3D 件
├── Host computer/                     # 上位機（讀每秒一行 RPM）
└── VSCode/esp32_code/                 # ★韌體（本文件焦點）
    ├── platformio.ini
    └── src/
        ├── main.cpp                   # 開機、START、Serial 除錯、協調急停畫面
        ├── settings/settings.h        # ★所有常數、狀態結構、NVS 欄位、記憶體保護介面
        ├── settings/settings.cpp      # ★4 顆自旋鎖(portMUX_TYPE)的實體
        ├── pins/pins.h                # GPIO 對照
        ├── RTOS/RTOS.h                # 任務優先權／核心
        ├── soft_i2c/soft_i2c.h        # 軟體 I2C（OLED／INA）
        ├── speed_sensor/              # 測速模組
        ├── motor_PID/                 # 開環起動 + sTune + PID 定速
        ├── board_ui/                  # OLED 顯示
        └── ina232/                    # 電壓電流功率
    ```

**改參數的第一入口永遠是：`src/settings/settings.h`。**  
腳位改 `pins/pins.h`，任務優先權改 `RTOS/RTOS.h`。  
**讀寫任何共享狀態一律透過 `settings.h` 提供的 `xxx_get_yyy()`/`xxx_set_yyy()` 介面**（詳見第 6 章），不要直接碰 `settings`/`PID_settings`/`ina_settings`/`ui_settings` 的欄位。

---

## 2. 硬體接線（與程式對應）

| 功能 | GPIO | 定義 | 備註 |
|---|---|---|---|
| 光柵測速 | 36 | `SPEED_SENSOR_PIN` | MCPWM Capture，雙沿 |
| 馬達 PWM | 26 | `MOTOR_PWM_PIN` | LEDC，20 kHz，10-bit（0~1023） |
| START 鈕 | 15 | `START_PIN` | 對 GND；內部上拉；按下=LOW |
| OLED SDA/SCL | 33/25 | `SDA_PIN`/`SCL_PIN` | 軟體 I2C；對應 PCB `/SDA2`/`/SCL2` |
| INA232 SDA/SCL | 21/22 | `SDA2_PIN`/`SCL2_PIN` | 軟體 I2C；板端可能無外接上拉 |
| Servo / Buck | 23 / 14 | 已定義，目前韌體未驅動 | 預留給後續 MPPT／致動 |

INA232 預設位址 `0x40`（A0→GND），分流電阻 `0.1Ω`。

---

## 3. 執行環境與依賴

`platformio.ini`：

- board：`mhetesp32devkit`
- framework：`arduino`（pioarduino，底層 IDF ~5.5.4）
- monitor：`115200`
- 函式庫：
  - `QuickPID`：閉環 PID
  - `sTune`：開環自動調參
  - `U8g2`：OLED

---

## 4. RTOS 任務地圖

| 任務 | 核心 | 優先權 | 誰啟動 | 職責 |
|---|---|---|---|---|
| `motor_PID` | Core 0 | 16 | START 後 `motor_PID_start()` | 開環階梯、sTune、PID、PWM 輸出 |
| `speed_sensor` | Core 0 | 15 | START 後 `speed_sensor_start()` | Capture ISR、轉速計算、無脈衝看門狗、喚醒 PID |
| `ina232` | Core 0 | 4 | `setup()` 即啟動 | 週期讀 INA232 + EMA |
| `board_ui` | Core 1 | 8 | `setup()` 即啟動 | OLED 刷新（純顯示） |
| Arduino `loop()` | Core 1 | 1（預設） | 框架 | START 鈕、Serial DBG、急停協調 |

重點：

- **按 START 之前不會轉馬達**（測速／PID 任務尚未建立）。
- `speed_sensor` 每個 `read_space`（預設 15 ms）對 PID 做 `xTaskNotifyGive`。
- `loop()` 必須 `vTaskDelay(1)`，否則會餓死 IDLE、觸發 Task WDT、造成卡頓與按鍵失靈。

---

## 5. 整機生命週期（從上電到定速）

```
上電
  ├─ setup(): Serial / START / OLED / INA232 / UI 任務
  └─ UI = WAIT_START（螢幕：Press START）

按 START（第一次）
  ├─ motor_PID_start() + speed_sensor_start()
  └─ UI = RUNNING

馬達控制狀態機（settings.init_phase）
  STEP_UP  → 每次升高一階 PWM，等 settle
  PROBE    → settle 後抓「之後第一筆」同位置轉速
  LEARNING → 轉速夠了就固定 PWM，觀察 N 圈就緒
  READY    → const_speed_ready=true
  PID_TUNE → sTune 自動調參（可跳過）
  PID_RUN  → QuickPID 閉環；可能置位 speed_stable=true

再按 START（RUNNING 中）
  └─ ESTOP 鎖定（fault=FAULT_ESTOP），需重開機
```

任一保護觸發 → `FAULT`，PWM=0，需重開機。

---

## 6. 共享狀態（其他模組該讀什麼）

都在 `settings.h`。**這 4 個結構體都被多個 FreeRTOS 任務、甚至 ISR 同時存取，
一律不要直接讀寫欄位，改用下面的 thread-safe 介面。**

### 6.0 執行緒安全存取介面（新模組必讀）

**為什麼需要它**：`volatile` 只保證編譯器不會把值快取在暫存器裡，並不能保證
「一次改好幾個相關欄位」不會被其他任務／ISR 插隊到一半，也不保證「同時讀好幾個
欄位」彼此是同一個時間點的值。因此 `settings.h` 用 4 顆獨立的自旋鎖
(`portMUX_TYPE`，實體在 `settings.cpp`) + 一套產生好的 get/set 函式來取代直接
存取：

| 鎖 | 保護的結構 | 保護的全域變數 |
|----|---|---|
| `g_speed_mux` | `speed_sensor` | `settings` |
| `g_pid_mux` | `motor_PID` | `PID_settings` |
| `g_ina_mux` | `ina232_sensor` | `ina_settings` |
| `g_ui_mux` | `board_ui` | `ui_settings` |

分成 4 顆而非共用 1 顆，是讓互不相關的模組不會互相卡住（例如 ina232 更新電壓
電流時，不該讓 speed_sensor 的 ISR 或 motor_PID 的控制迴圈等待）。

**API 命名規則**（由 `settings.h` 內的巨集自動產生，每個欄位都有）：

```cpp
speed_get_now_speed()          / speed_set_now_speed(v)      // speed_sensor 欄位
pid_get_keep_rpm()             / pid_set_keep_rpm(v)          // motor_PID 欄位
ina_get_bus_V()                / ina_set_bus_V(v)             // ina232_sensor 欄位
ui_get_state()                 / ui_set_state(v)              // board_ui 欄位
```

即「前綴(struct 簡稱) + `_get_`/`_set_` + 欄位名稱」，對照 `settings.h` 裡
`SETTINGS_SCALAR_ACCESSOR(...)` / `SETTINGS_SCALAR_GETTER(...)`（唯讀）那幾行
就能查到每個欄位實際有哪些函式可用。測速環形緩衝這種好幾個欄位綁在一起才有意義
的資料，改走專用函式：`speed_capture_push_edge()`（只給 ISR 寫入用）、
`speed_capture_snapshot()`（任務端整組讀出）、`speed_capture_mark_used()`。

**需要一次讀寫多個相關欄位、要求彼此一致時**，用 `SettingsLockGuard`（RAII，
離開作用域自動解鎖）直接包住整段：

```cpp
{
    SettingsLockGuard lock(g_speed_mux);   // 依你要動的結構選對應的鎖
    settings.fault = true;
    settings.fault_code = code;
    settings.init_phase = SPEED_PHASE_FAULT;
} // 離開這裡自動解鎖
```

**使用規則（務必遵守）**：

1. 鎖內只能放「幾行欄位讀寫」，**嚴禁**在鎖內呼叫 `Preferences`(NVS/Flash)、
   `Serial`、`delay()` 等耗時或會被中斷的函式（鎖住期間會關閉本核心中斷）。
   需要存 Flash 時，先在鎖內把值複製到區域變數，解鎖後再對區域變數做 I/O
   （寫法參考 `settings.h` 內 `motor_PID::load()` / `::save()`）。
2. **不同的鎖不要巢狀持有**（例如持有 `g_pid_mux` 時又去呼叫會拿 `g_speed_mux`
   的函式）。目前全專案都遵守「同一時間只持有一顆鎖」，避免兩顆鎖交叉鎖死。
   自己結構內部的欄位可以巢狀存取同一顆鎖沒關係（ESP-IDF 自旋鎖對同核心可重入）。
3. 誰是這個結構的「擁有模組」（`speed_sensor.cpp` 擁有 `settings`、
   `motor_PID.cpp` 擁有 `PID_settings`…）可以用 `SettingsLockGuard` 直接讀寫
   自己結構的多個欄位；**跨模組**一律只用 get/set 函式，不要直接碰欄位。

**新增模組照抄這個模式即可**：宣告自己的 `struct` + 一顆 `portMUX_TYPE`
（在 `settings.cpp` 定義實體），欄位一行一個 `SETTINGS_SCALAR_ACCESSOR(...)`，
就能自動獲得同一等級的保護，不必重新設計鎖的邏輯。

### 6.1 `settings`（`speed_sensor` 結構）— 測速與協調核心

| 欄位 | 意義 | 存取函式 | 誰寫 | 誰讀 |
|---|---|---|---|---|
| `now_speed` | 目前轉速 RPM（EMA 後） | `speed_get/set_now_speed` | speed_sensor | 全員 |
| `speed_valid` | 轉速是否可信 | `speed_get/set_speed_valid` | speed_sensor | PID／UI |
| `read_space` | 測速／PID 週期 ms（預設 15） | `speed_get/set_read_space` | 預設／可改 | 兩模組 |
| `init_phase` | 階段碼 | `speed_get/set_init_phase` | 兩邊 | UI／DBG |
| `const_speed_ready` | 測速就緒，可進調參／定速 | `speed_get/set_const_speed_ready` | speed_sensor | motor_PID |
| `rpm_stable` | **內部**：開環已 hold（不是對外穩調） | `speed_get/set_rpm_stable` | 兩邊 | DBG |
| **`speed_stable`** | **對外穩調旗標**（其他模組請用這個） | `speed_get/set_speed_stable` | motor_PID 為主 | 任何模組 |
| `ol_pwm_cmd` | 目前 PWM 指令（開環或閉環） | `speed_get/set_ol_pwm_cmd` | motor_PID | 看門狗／DBG |
| `ol_hold` | 固定開環 PWM 中 | `speed_get/set_ol_hold` | motor_PID | speed_sensor |
| `ol_probe_request/ready/rpm` | 階梯 probe 協議 | `speed_get/set_ol_probe_*` | 兩邊 | DBG |
| `settle_samples` | LEARNING 已觀察圈數 | `speed_get/set_settle_samples` | speed_sensor | DBG |
| `fault` / `fault_code` | 故障鎖定 | `speed_get/set_fault[_code]` | 任一保護路徑 | 全員 |
| `edge_count` | 絕對邊緣數 | `speed_get_edge_count`（唯讀） | ISR | DBG |
| `buf_idx`/`count_number` | 環形緩衝指標／快照 | `speed_capture_*()` 專用函式 | ISR／speed_sensor | DBG |

### 6.2 `PID_settings`（`motor_PID` 結構）

| 欄位 | 意義 | 存取函式 |
|---|---|---|
| `keep_rpm` | 定速目標 RPM（NVS 可存；0 時調參前會鎖當前轉速） | `pid_get/set_keep_rpm` |
| `Kp/Ki/Kd` | PID 增益（NVS） | `pid_get/set_Kp`／`Ki`／`Kd` |
| `tuned` | NVS：是否調過 | `pid_get/set_tuned` |
| `autotune_active/done` | 本次上電調參狀態 | `pid_get/set_autotune_active`／`_done` |
| `pwm_freq=20000`、`pwm_res=10` | LEDC 參數 | `pid_get/set_pwm_freq`／`pwm_res` |

NVS namespace：`pid_cfg`（`Kp`,`Ki`,`Kd`,`tuned`,`keep_rpm`）。  
`load()`/`save()` 內部已處理好鎖與 Flash I/O 的順序，直接呼叫 `PID_settings.load()` /
`PID_settings.save()` 即可，不需額外加鎖。

### 6.3 `ina_settings`

| 欄位 | 存取函式 |
|---|---|
| `bus_V`／`current_A`／`power_W`／`shunt_mV` | `ina_get/set_bus_V` 等 |
| `online`／`data_valid` | `ina_get/set_online`／`data_valid` |
| `sample_count` | `ina_get_sample_count`（唯讀）；遞增用 `ina_increment_sample_count()` |

### 6.4 `ui_settings`

| 欄位 | 存取函式 |
|---|---|
| `state`：`WAIT_START` / `RUNNING` / `ESTOP` | `ui_get/set_state` |
| `motor_started` | `ui_get/set_motor_started` |
| `oled_ok` | `ui_get/set_oled_ok` |

---

## 7. 測速模組（`speed_sensor`）詳解

### 7.1 硬體原理

- MCPWM Capture，時鐘 **80 MHz**
- GPIO36，**上升沿 + 下降沿**
- 光柵格數：`space_number = 2` → 每圈邊緣數 `EDGES_PER_REV = 4`
- 環形緩衝：`2^buf_idx_bit = 16` 筆時間戳

公式：

\[
\text{RPM} = \frac{80\times10^6 \times 60}{\text{同一物理位置相隔一整圈的 ticks}}
\]

程式常數：`RPM_CONSTANT = 80e6 * 60`。

### 7.2 為什麼堅持「同位置整圈」？

3D 列印光柵每格寬度有誤差。若用「相鄰格」算瞬時轉速，誤差會很大。  
用 **同一個遮光/透光位置，隔一整圈** 的時間差，幾何誤差會互相抵銷。

早期曾做「格距誤差補償 + 單格量測」以提高更新率，但實測：

- 單格時間基準只有 1/4 圈，雜訊被放大
- 本機台 PWM→RPM 增益極高（約每 1 count 十幾 RPM）
- 雜訊進 PID 會造成 0↔滿載硬切

**現行策略：控制迴路一律只用同位置整圈 + 輕量 EMA。**  
`LEARNING` 不再學格距權重，只做「固定 PWM 後觀察夠多圈」。

### 7.3 ISR 去彈跳

若兩次邊緣間隔對應轉速 > `RPM_RUNAWAY_MAX × MIN_EDGE_TICKS_SAFETY_RPM_MULT`（預設 2.5 倍），視為彈跳，**丟棄不入緩衝**。

### 7.4 低轉速「probe 補丁」

開環每升一階 PWM 後：

1. 等 `MOTOR_STEP_SETTLE_MS`（250 ms）
2. `ol_probe_request=true`
3. 只接受 **請求之後** 的第一筆新同位置轉速 → `ol_probe_rpm`
4. 不拿「保持舊值」冒充當前轉速（避免低轉速誤判）

門檻：`probe_rpm >= RPM_INIT_READABLE + RPM_INIT_MARGIN`（1000+150=**1150 RPM**）  
達標 → `ol_hold=true`，進入 LEARNING。

### 7.5 LEARNING / READY

固定 PWM 後，每來一個有效同位置樣本：`settle_samples++`  
達 `READY_SETTLE_MIN_SAMPLES`（24）→ `const_speed_ready=true`。

### 7.6 EMA 濾波

```
speed_filter_ema += SPEED_FILTER_ALPHA * (rpm_same - speed_filter_ema)
```

預設 `SPEED_FILTER_ALPHA = 0.3`。  
`now_speed` 輸出的是濾波後值（給 keep_rpm 鎖定與 PID）。

### 7.7 無新邊緣時的行為

| 情況 | 行為 |
|---|---|
| probe 等待中 | `speed_valid=false`，不拿舊值決策 |
| 距上邊緣 ≤ 300 ms | 保持上次轉速 |
| > 300 ms | 視為停轉，`now_speed=0`；若尚未就緒則重置觀察進度 |

---

## 8. 馬達控制模組（`motor_PID`）詳解

### 8.1 PWM

- LEDC attach：`MOTOR_PWM_PIN`，20 kHz，10-bit → **0~1023**
- 開環上限：`MOTOR_STARTUP_PWM_MAX_RATIO = 0.70` → 最大約 716
- 每階：`MOTOR_PWM_STEP_RATIO = 0.05` → 約 51 count／階

### 8.2 階梯開環流程

```
pwm += step
等 250ms
請求 probe
  ├─ 逾時 400ms 無資料 → 當 0 RPM → 再升階
  ├─ < 1150 → 再升階
  ├─ 已到 70% 仍不夠 → FAULT_PWM_MAX_NO_SPEED
  └─ ≥ 1150 → hold，進 LEARNING
```

### 8.3 sTune 自動調參（測速就緒後）

**啟用條件**

- `PID_AUTOTUNE_ENABLE=1`
- `PID_AUTOTUNE_EVERY_BOOT=1` → 每次上電都調  
  （改 `0` 則只在 NVS `tuned=false` 時調）

**為何不用早期的 ZN_PID + directIP？**

實測問題：

- 反曲點法容易被超調／震盪騙到過大製程增益
- Kd 在 15 ms 取樣下被放大，造成 bang-bang
- sTune 的 Kp 是「正規化增益」，直接餵 QuickPID 會再放大約 `inputSpan/outputSpan` 倍

**現行策略**

| 項目 | 現行 |
|---|---|
| 動作 | `direct5T`（完整 5τ 測試） |
| 規則 | `NoOvershoot_PI`（**只用 PI，Kd=0**） |
| 步階 | 目前 duty + 8% max（`PID_TUNE_STEP_RATIO`） |
| settle | 3 s |
| test 上限 | 25 s |
| pre-settle | 就緒後先等 500 ms 再鎖 `keep_rpm` |
| inputSpan | `max(2000, now_speed×4)`，且 ≤ runaway |
| eStop | `RPM_RUNAWAY_MAX × 0.75` |
| 增益換算 | 用真實製程增益重算 Kp/Ki，再 × `PID_TUNE_GAIN_SCALE(0.8)` |
| Tau/td 上限 | 20（防死時間量太小暴衝） |
| 總逾時 | settle+test+10s |

調參完成 → 存 NVS → `PID_RUN`。

### 8.4 閉環 PID

- `QuickPID`，anti-windup：`iAwClamp`
- 取樣：`read_space × 1000` µs
- **輸出斜率限制**：每週期最多變 `PID_OUTPUT_SLEW_MAX`（60 count）  
  避免 0↔1023 硬切。
- 目標：`PID_settings.keep_rpm`

### 8.5 `speed_stable`（對外穩調旗標）

**只有全部成立才可能變 true：**

1. 無 fault  
2. `const_speed_ready`  
3. `autotune_done` 且非調參中  
4. `init_phase == PID_RUN`  
5. `speed_valid` 且 `now_speed ≥ 1000`  
6. `keep_rpm > 1`  
7. 連續 `SPEED_STABLE_NEED_HITS`(20) 次貼近目標  
   （|err|≤40 RPM **或** 相對誤差≤2.5%）

**立刻變 false：**

- 換 `keep_rpm`
- 偏離目標
- 初始化／調參／故障／停轉／不可信

其他模組（例如未來 MPPT）應讀：

```cpp
if (settings.speed_stable) { /* 可以開始依賴定速的工作 */ }
```

不要誤用 `rpm_stable`（那只是開環 hold 內部旗標）。

---

## 9. 保護程序總表

| 代號 | 名稱 | 觸發條件 | 動作 |
|---|---|---|---|
| 1 | `FAULT_RUNAWAY_RPM` | `now_speed > RPM_RUNAWAY_MAX`（現行 **17000**） | PWM=0，鎖定 |
| 2 | `FAULT_NO_PULSE_TIMEOUT` | **只要 `ol_pwm_cmd>0`**，連續 `NO_PULSE_TIMEOUT_MS`(200ms) 無新邊緣 | 同上（通電看門狗，全階段） |
| 3 | `FAULT_PWM_MAX_NO_SPEED` | 開環到 70% 仍达不到 1150 RPM | 同上 |
| 4 | `FAULT_AUTOTUNE_FAIL` | 增益無效／製程參數無效／調參總逾時 | 同上 |
| 5 | `FAULT_ESTOP` | RUNNING 時再按 START | 同上 + UI_ESTOP |

共同後果：

- `fault=true`，`init_phase=FAULT`
- `const_speed_ready=false`，`speed_stable=false`
- PWM 強制 0
- **需重開機**才能恢復（刻意設計）

診斷用（不鎖機）：

- `SPEED_JUMP_WARN_RPM`：定速中單週期跳變過大 → `[EVT] speed jump ...`
- `SPEED_EDGE_GAP_WARN_MS`：定速中邊緣間隔過長 → `[EVT] edge gap warn ...`

---

## 10. UI / START / INA232

### 10.1 START（`main.cpp`）

- `INPUT_PULLUP` + IDF pull-up  
- ISR 僅設旗標；`loop` 做 debounce（40 ms）  
- `WAIT_START` + 按下邊緣 → 啟動馬達任務  
- `RUNNING` + 按下邊緣 → ESTOP  
- 其他模組 fault 時，UI 自動切 `ESTOP` 畫面

### 10.2 OLED（`board_ui`）

- 軟體 I2C，可強制／自動 SSD1306 或 SH1106（`OLED_CONTROLLER_FORCE`）  
- 顯示：狀態、RPM、PWM、V/I/P、fault  
- **不負責按鍵**（避免軟 I2C 卡住漏按）

### 10.3 INA232

- 軟體 I2C @ 100 kHz（無外接上拉時必須慢）  
- 晶片 AVG=1；ESP32 做 EMA（`INA232_FILTER_ALPHA=0.2`）  
- 任務週期 1 ms，優先權低，不搶控制迴路

### 10.4 SoftI2C 為何自己寫？

Arduino-ESP32 3.x 硬體 I2C 在 NACK 後可能卡 `INVALID_STATE`。  
且熱路徑若每 bit 呼叫 `pinMode()` 會極慢（OLED 一幀可卡數百 ms）。  
現行：開汲極 + 內部上拉，熱路徑只動 `gpio_set_level`。

---

## 11. Serial 除錯協定

鮑率 **115200**。

| 前綴 | 內容 |
|---|---|
| `[BOOT]` | 上電參數摘要 |
| `[MAIN]` | START／ESTOP |
| `[EVT]` | 階段／旗標／故障／跳變警告（事件） |
| `[DBG]` | 每 250 ms 狀態總覽 |
| `[TUNE]` | 調參進度／結果 |
| `[SPD]` | 看門狗等 |
| 純數字行 | 每秒一行 `now_speed`（上位機相容；非數字行會被上位機忽略） |

`[DBG]` 重要欄位解讀：

- `phase`：狀態機  
- `rpm` / `keep`：實際／目標  
- `pwm`：目前 duty  
- `settle=a/b`：就緒觀察進度  
- `ready`：`const_speed_ready`  
- `speed_stable`：對外穩調  
- `tune=active/done`  
- `V/I/P`：INA232  

---

## 12. 預設值速查（現行 `settings.h`）

### 測速／起動

| 常數 | 預設 | 意義 |
|---|---|---|
| `space_number` | 2 | 光柵格數 |
| `buf_idx_bit` | 4 | 緩衝深度 16 |
| `read_space` | 15 ms | 測速／PID 週期 |
| `RPM_INIT_READABLE` | 1000 | 可讀門檻 |
| `RPM_INIT_MARGIN` | 150 | → 實際要 ≥1150 |
| `MOTOR_PWM_STEP_RATIO` | 0.05 | 每階 5% |
| `MOTOR_STEP_SETTLE_MS` | 250 | 升階後等待 |
| `MOTOR_PROBE_TIMEOUT_MS` | 400 | probe 逾時 |
| `MOTOR_STARTUP_PWM_MAX_RATIO` | 0.70 | 開環上限 |
| `READY_SETTLE_MIN_SAMPLES` | 24 | LEARNING 圈數 |
| `SPEED_STALL_TIMEOUT_MS` | 300 | 無邊緣當停轉 |
| `SPEED_FILTER_ALPHA` | 0.3 | RPM EMA |
| `MIN_EDGE_TICKS_SAFETY_RPM_MULT` | 2.5 | ISR 去彈跳 |

### 保護

| 常數 | 預設 |
|---|---|
| `RPM_RUNAWAY_MAX` | 17000 |
| `NO_PULSE_TIMEOUT_MS` | 200 |

### PID／調參

| 常數 | 預設 |
|---|---|
| `PID_AUTOTUNE_ENABLE` | 1 |
| `PID_AUTOTUNE_EVERY_BOOT` | 1 |
| `PID_TUNE_SETTLE_SEC` | 3 |
| `PID_TUNE_TEST_SEC` | 25 |
| `PID_TUNE_SAMPLES` | 250 |
| `PID_TUNE_STEP_RATIO` | 0.08 |
| `PID_TUNE_GAIN_SCALE` | 0.8 |
| `PID_TUNE_PRE_SETTLE_MS` | 500 |
| `PID_OUTPUT_SLEW_MAX` | 60 |
| `SPEED_STABLE_*` | 40 RPM / 2.5% / 20 hits |

### UI／INA

| 常數 | 預設 |
|---|---|
| `START_DEBOUNCE_MS` | 40 |
| `UI_REFRESH_MS` | 200 |
| `I2C_INA_FREQ_HZ` | 100000 |
| `INA232_RSHUNT_OHM` | 0.1 |
| `INA232_IMAX_A` | 0.8 |

---

## 13. 我要怎麼改？（實務指南）

### 13.1 光柵格數改了

改 `space_number`。  
雙沿時 `EDGES_PER_REV` 會自動變。確認機械上每圈邊緣數正確。

### 13.2 馬達太肉／太兇（開環爬不上去或太快）

- 爬不上去：加大 `MOTOR_PWM_STEP_RATIO` 或 `MOTOR_STARTUP_PWM_MAX_RATIO`  
- 太兇：減小步階、加長 `MOTOR_STEP_SETTLE_MS`  
- 1150 門檻不適合：改 `RPM_INIT_READABLE` / `RPM_INIT_MARGIN`

### 13.3 無脈衝看門狗誤觸／太慢

改 `NO_PULSE_TIMEOUT_MS`：

- 誤觸（啟動瞬間就 FAULT）→ 加大（如 300~500）  
- 希望更快斷電 → 减小（但勿小於正常最大脈衝間隔）

### 13.4 飛車太敏感／太鬆

改 `RPM_RUNAWAY_MAX`。  
調參期 eStop 是它的 75%（`PID_TUNE_ESTOP_RATIO`）。

### 13.5 定速震盪（pwm 狂切、RPM 晃）

優先檢查：

1. `PID_OUTPUT_SLEW_MAX` 是否夠小  
2. 是否又打開了 D 項（現行應為 PI，`Kd=0`）  
3. `SPEED_FILTER_ALPHA` 略降可更平滑  
4. `PID_TUNE_GAIN_SCALE` 再降（如 0.5）  
5. 設 `PID_AUTOTUNE_EVERY_BOOT 0`，用已存 NVS 參數對照  
6. 手動寫死 Kp/Ki（改 `load()` 預設或 NVS）

### 13.6 不想每次上電都自動調參

```cpp
#define PID_AUTOTUNE_EVERY_BOOT 0
```

或

```cpp
#define PID_AUTOTUNE_ENABLE 0
```

### 13.7 固定目標轉速

- 調參前把 `PID_settings.keep_rpm` 設成目標（或 NVS 寫入）  
- 若保持 0，程式會在 pre-settle 後鎖「當前濾波轉速」當目標

### 13.8 換 OLED 全黑

試：

```cpp
#define OLED_CONTROLLER_FORCE 2  // SH1106
```

### 13.9 新增「定速後才做事」的模組

```cpp
#include "settings/settings.h"

if (!speed_get_fault() && speed_get_speed_stable()) {
    // 安全：轉速已穩在 keep_rpm
}
```

不要直接讀 `settings.fault`／`settings.speed_stable` 欄位，一律用
`speed_get_fault()`／`speed_get_speed_stable()`（見第 6.0 節的執行緒安全介面）。
若你的新模組要維護自己的共享狀態，照抄 `settings.h` 的模式：宣告
`struct` + 一顆 `portMUX_TYPE`（實體放 `settings.cpp`）+ `SETTINGS_SCALAR_ACCESSOR(...)`
逐欄位產生 get/set，就能自動獲得同一等級的保護。

### 13.10 清除 NVS 舊 PID

序列埠監控無法直接清時，可暫時在 `setup` 呼叫清除，或改 Preferences namespace，或用 esptool erase。  
欄位在 `pid_cfg`。

---

## 14. 模組協作時序（簡圖）

```
ISR(光柵邊緣) ──寫 cap_buffer──►
                                 │
speed_sensor 每 15ms：快照→算 RPM→保護→notify PID
                                 │
motor_PID：等待 notify
  ├─ 未就緒：階梯開環 / hold
  ├─ 就緒且未調完：sTune
  └─ 就緒且已調完：PID + slew + 更新 speed_stable
                                 │
main loop：START / ESTOP / Serial / 1ms yield
board_ui：畫 OLED
ina232：讀電氣量
```

---

## 15. 已知設計取捨（讀 code 時別踩雷）

1. **故障後不自動復歸** — 安全取向，必須重開機。  
2. **`rpm_stable` ≠ `speed_stable`** — 前者開環內部，後者對外。  
3. **控制不用單格補償** — 精度用同位置整圈換穩定。  
4. **sTune 原始 Kp 不能直接餵 QuickPID** — 必須做單位換算（已在 `tunings` 分支做）。  
5. **START 不放在 UI 任務** — 避免軟 I2C 阻塞漏按。  
6. **PCB 絲印 SDA/SCL 與直覺對調** — 以 `pins.h` 註解為準。  
7. **上位機只吃純數字 RPM 行** — DBG 行請保留非純數字前綴。  
8. **4 顆自旋鎖、刻意不互相巢狀** — `g_speed_mux`/`g_pid_mux`/`g_ina_mux`/`g_ui_mux`
   各自獨立，任何函式都不會在持有一顆的情況下又去拿另一顆，避免交叉鎖死；
   跨模組讀寫共享欄位一律走 `settings.h` 的 get/set 介面（見第 6.0 節）。

---

## 16. 建議閱讀／修改順序

若你要動手改：

1. `settings/settings.h` — 調行為／參數；新增共享欄位也在這裡加 struct 欄位 +
   對應的 `SETTINGS_SCALAR_ACCESSOR(...)`（見第 6.0 節）  
2. `settings/settings.cpp` — 只有新增「一整組結構」才需要動（多加一顆
   `portMUX_TYPE` 實體）  
3. `pins/pins.h` — 換腳  
4. `motor_PID/motor_PID.cpp` — 開環／調參／閉環  
5. `speed_sensor/speed_sensor.cpp` — 測速／看門狗  
6. `main.cpp` — START／除錯輸出  
7. `board_ui` / `ina232` — 顯示與電氣量測  

除錯時先看 Serial 的：

`phase` → `probe_rpm` → `settle` → `ready` → `tune` → `Kp/Ki/Kd` → `pwm` 是否仍 bang-bang → `speed_stable` → `fault`

---

## 17. 一句話總結

這份韌體做的是：**按 START → 階梯把馬達拉到可測轉速 → 同位置整圈測速就緒 →（可選）sTune 算出保守 PI → 斜率限制的閉環定速 → 用 `speed_stable` 告訴其他模組「可以開始依賴定速」；過程中任何飛車、通電無脈衝、調參失敗或再按 START 都會鎖定斷電。**

參數幾乎都在 `settings.h`；行為邏輯在 `speed_sensor` 與 `motor_PID`；人機在 `main` + `board_ui`；電氣在 `ina232`。

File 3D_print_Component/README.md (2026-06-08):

3D列印件分為二大部分 : 變速箱、外殼<br>
變速箱:內部主要為三個軸，主動力輸入軸(直徑15mm) 、換檔軸、變速軸<br>
變速箱齒輪命名規則 : 所處軸(1:主動力輸入軸 2:換檔軸 3:變速軸)_檔位(1~5)<br>

[回到主頁](../README.md)

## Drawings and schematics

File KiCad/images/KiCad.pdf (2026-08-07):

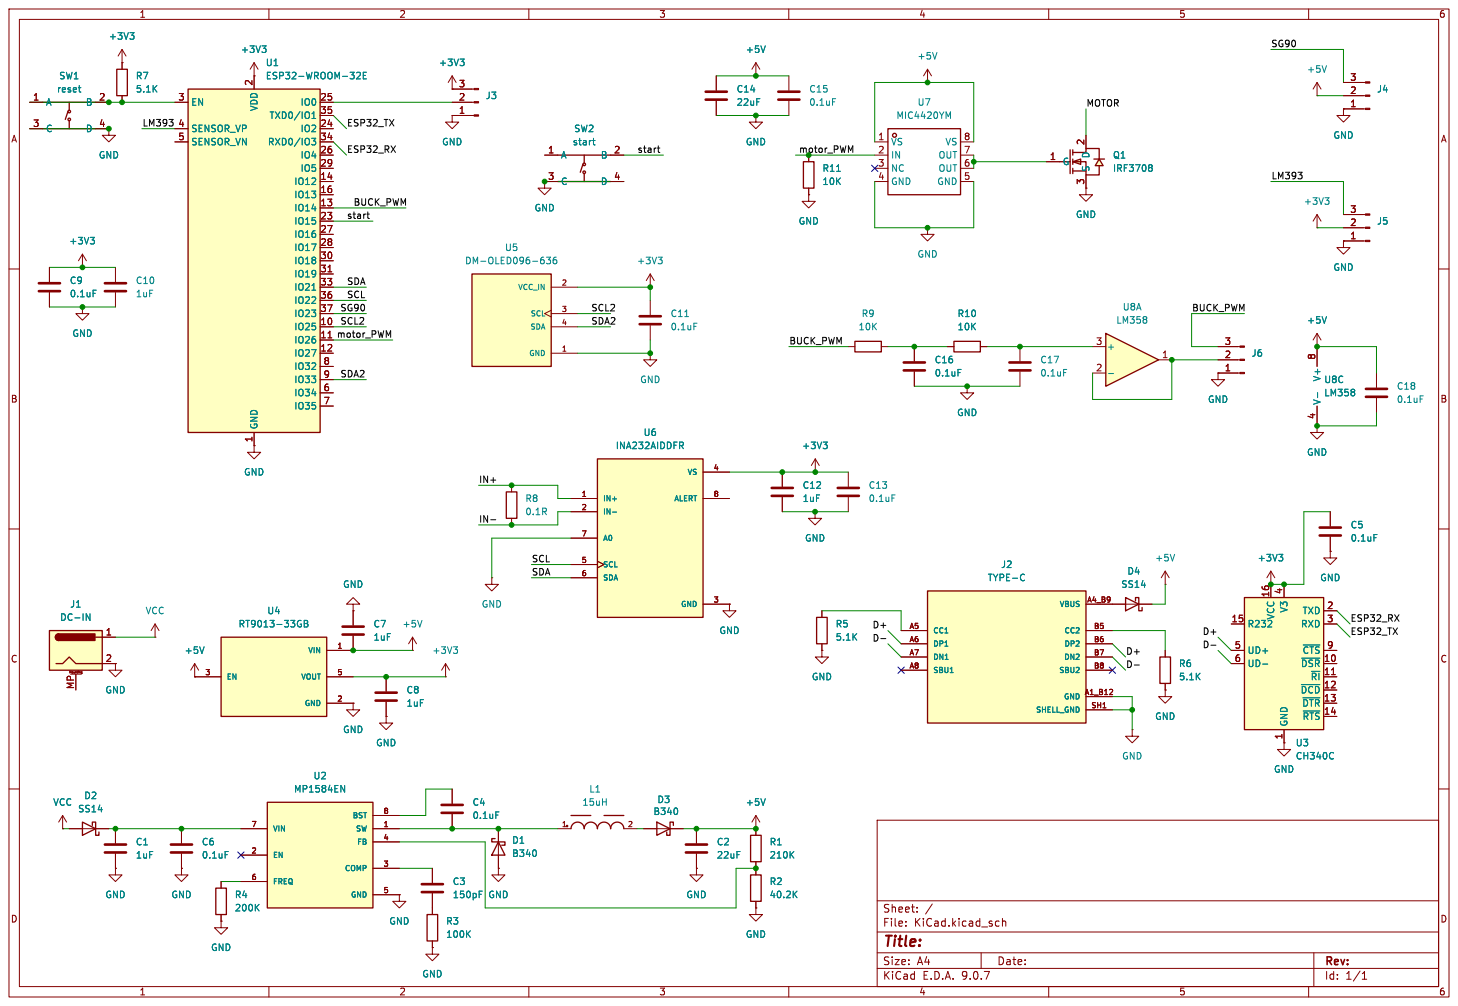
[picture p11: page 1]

1 TXD 2 RXD 3 ~{CTS}9 ~{DSR} 10 ~{RI} 11 ~{DCD} 12 ~{DTR} 13 ~{RTS} 14 D4 SS14 GND

1 TXD 2 RXD 3 ~{CTS}9 ~{DSR} 10 ~{RI} 11 ~{DCD} 12 ~{DTR} 13 ~{RTS} 14 U3 CH340C

Id: 1/1 Title: File: KiCad.kicad_sch Sheet: / C8

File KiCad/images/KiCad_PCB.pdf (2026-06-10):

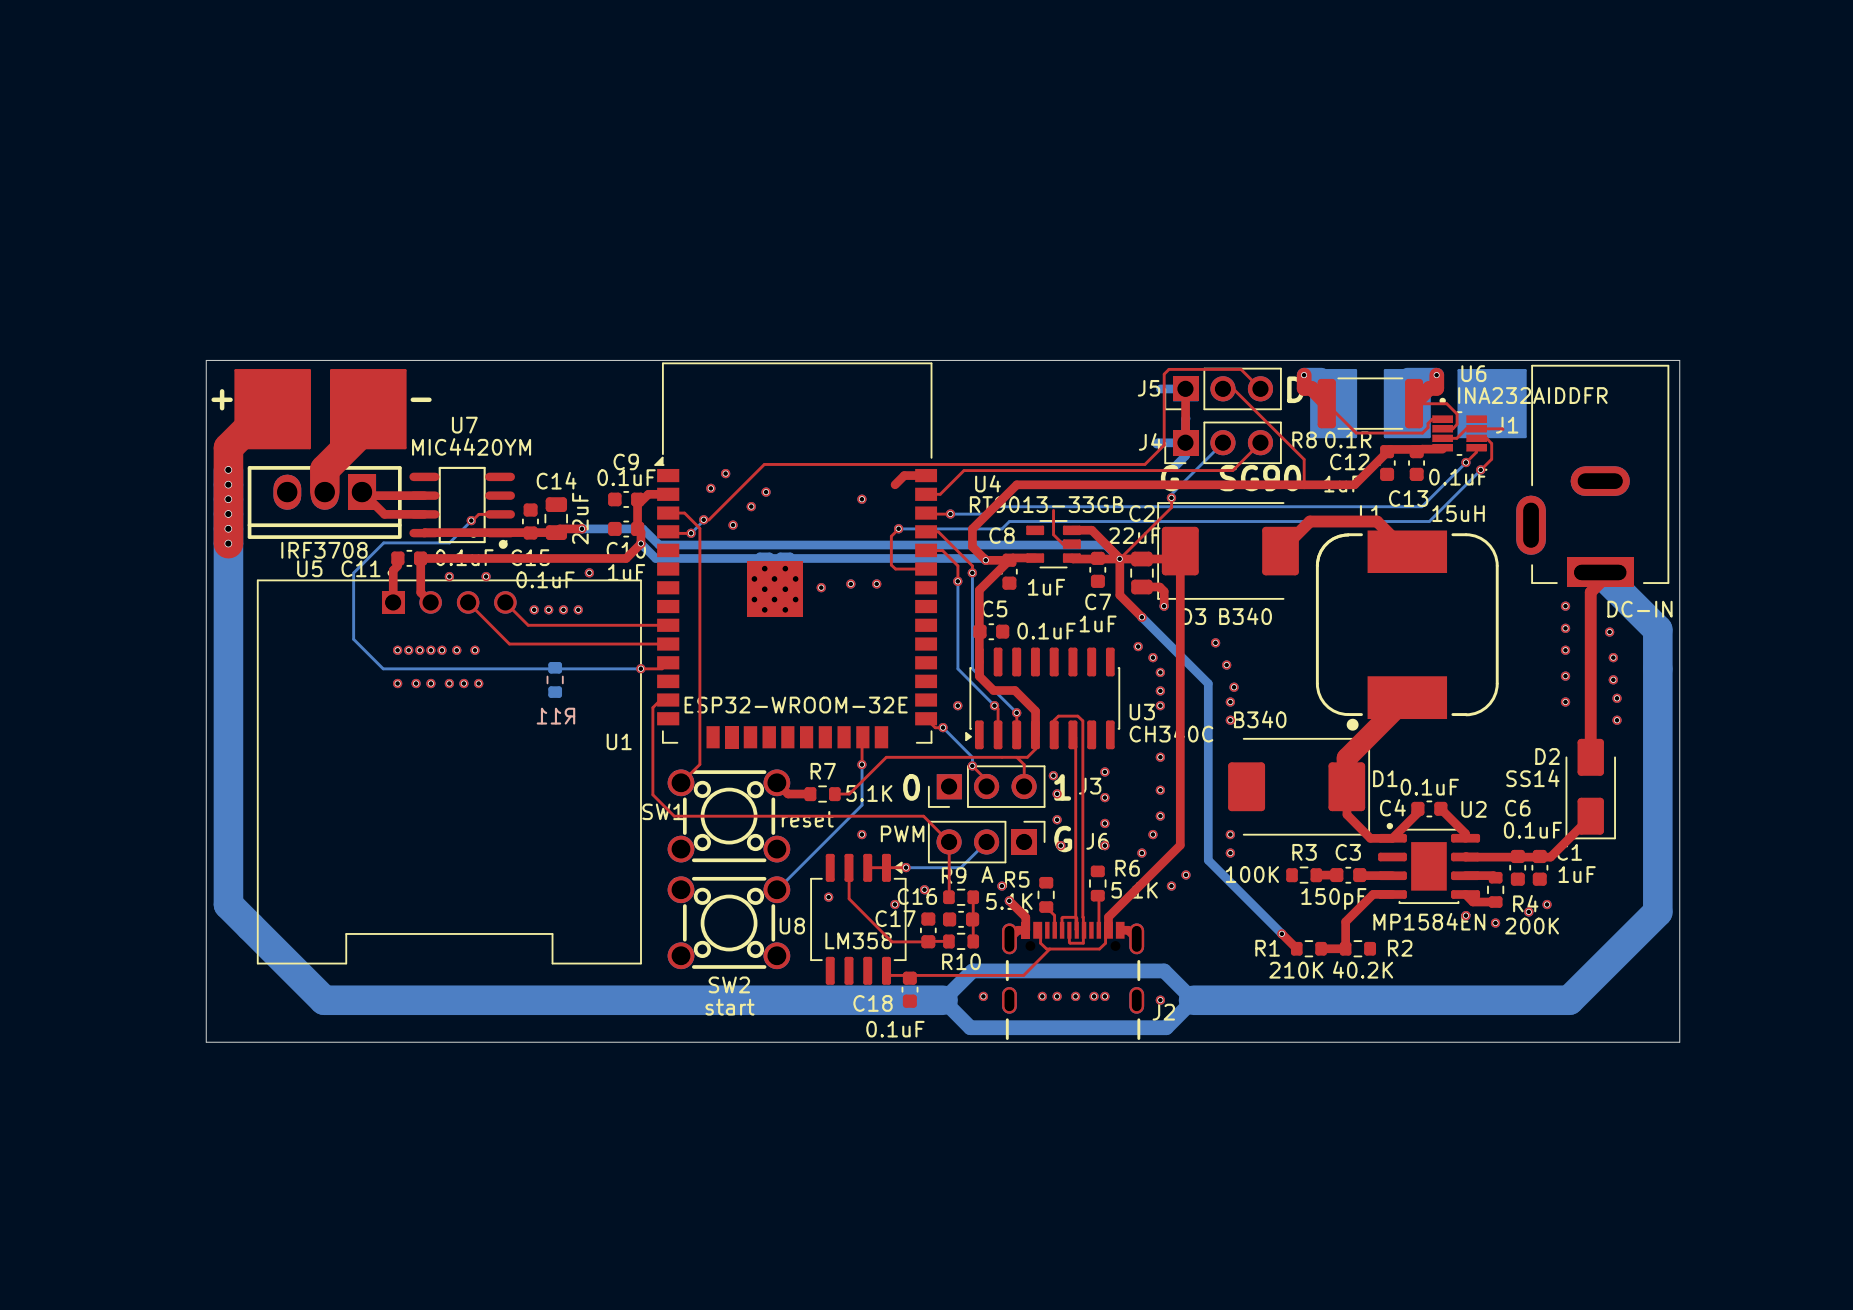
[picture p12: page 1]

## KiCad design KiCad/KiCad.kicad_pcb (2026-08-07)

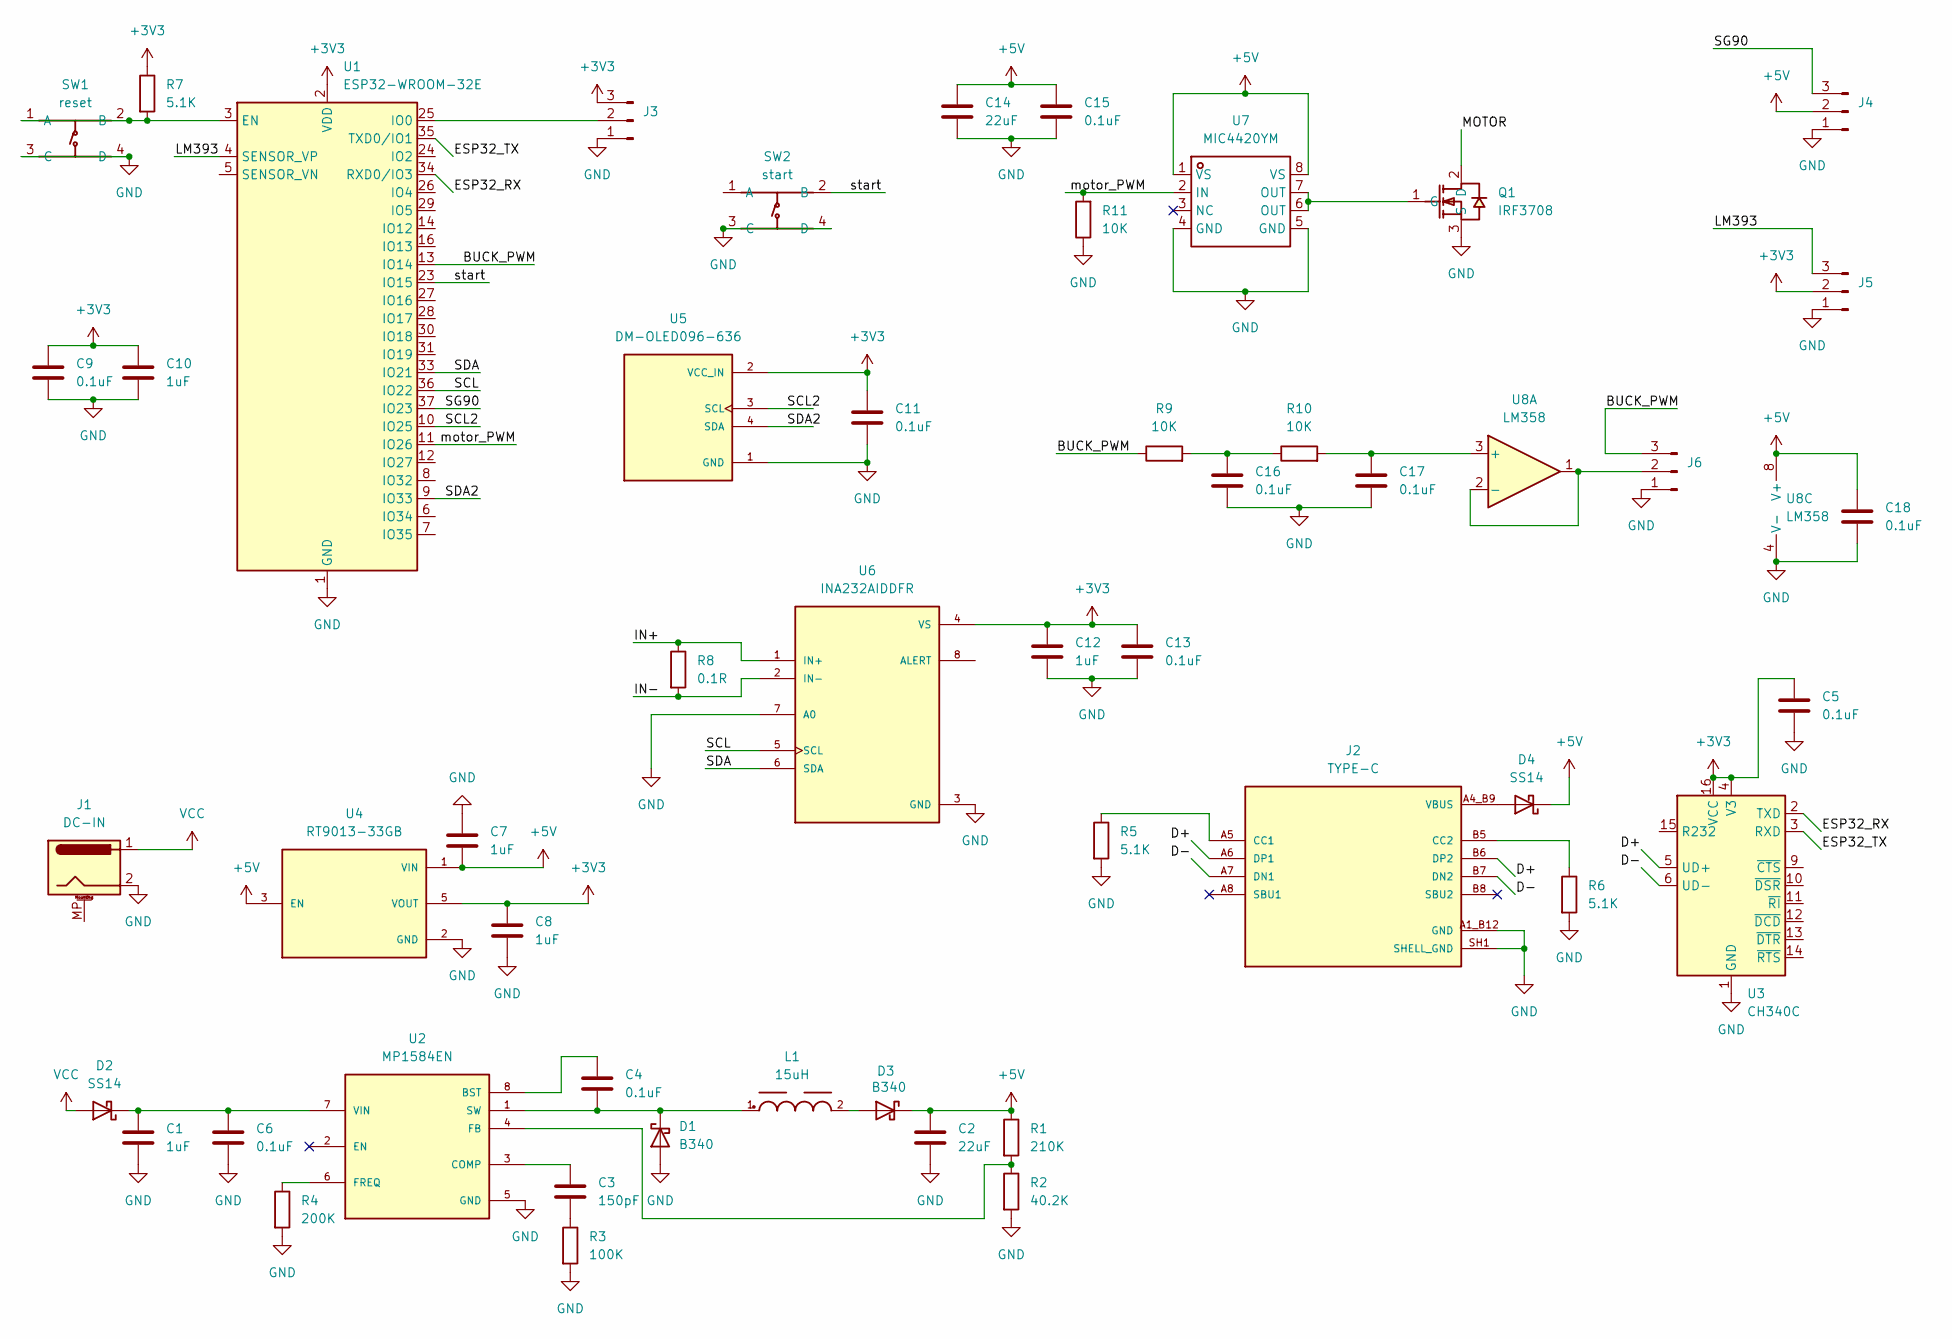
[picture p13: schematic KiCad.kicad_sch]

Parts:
C1, C7, C8, C10, C12: 1uF; C_0603_1608Metric
C2, C14: 22uF; C_0805_2012Metric
C3: 150pF; C_0603_1608Metric
C4, C5, C6, C9, C11, C13, C15, C16, C17, C18: 0.1uF; C_0603_1608Metric
D1, D3: B340; D_SMC
D2, D4: SS14; D_SMA
J1: DC-IN; BarrelJack_Kycon_KLDX-0202-xC_Horizontal
J2: TYPE-C; GCT_USB4105-GF-A; PARTREV B4
J3, J4, J5, J6: Conn_01x03_Pin; PinHeader_1x03_P2.54mm_Vertical
L1: 15uH; WE-PD_1260
Q1: IRF3708; TO-220-3_L10.0-W4.6-P2.54-L; LCSC Part C18212457
R1: 210K; R_0603_1608Metric
R2: 40.2K; R_0603_1608Metric
R3: 100K; R_0603_1608Metric
R4: 200K; R_0603_1608Metric
R5, R6, R7: 5.1K; R_0603_1608Metric
R8: 0.1R; R_2512_6332Metric
R9, R10, R11: 10K; R_0603_1608Metric
SW1: reset; SW-TH_4P-L6.0-W6.0-P4.50-LS6.5; LCSC Part C393938
SW2: start; SW-TH_4P-L6.0-W6.0-P4.50-LS6.5; LCSC Part C393938
U1: ESP32-WROOM-32E; ESP32-WROOM-32D
U2: MP1584EN; SOIC127P600X170-9N
U3: CH340C; SOIC-16_3.9x9.9mm_P1.27mm
U4: RT9013-33GB; SOT94P279X129-5N; PARTREV Aprill 2011
U5: DM-OLED096-636; MODULE_DM-OLED096-636; PARTREV 2018-09-10
U6: INA232AIDDFR; SOT65P280X110-8N; PARTREV December 2022
U7: MIC4420YM; SOIC-8_L4.9-W3.9-P1.27-LS6.0-BL; LCSC Part C637530
U8: LM358; SOIC-8_5.3x6.2mm_P1.27mm

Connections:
+3V3: C5.1, C8.1, C9.1, C10.1, C11.1, C12.1, C13.1, J3.3, J5.2, R7.1, U1.2 (VDD), U3.4 (V3), U3.16 (VCC), U4.5 (VOUT), U5.2 (VCC_IN), U6.4 (VS)
+5V: C2.1, C7.2, C14.1, C15.1, C18.1, D3.1 (K), D4.1 (K), J4.2, R1.1, U4.1 (VIN), U4.3 (EN), U7.1 (VS), U7.8 (VS), U8.8 (V+)
/BUCK_PWM: J6.3, R9.1, U1.13 (IO14)
/D+: J2.A6 (DP1), J2.B6 (DP2), U3.5 (UD+)
/D-: J2.A7 (DN1), J2.B7 (DN2), U3.6 (UD-)
/ESP32_RX: U1.34 (RXD0/IO3), U3.2 (TXD)
/ESP32_TX: U1.35 (TXD0/IO1), U3.3 (RXD)
/IN+: R8.1, U6.1 (IN+)
/IN-: R8.2, U6.2 (IN-)
/LM393: J5.3, U1.4 (SENSOR_VP)
/MOTOR: Q1.2 (D)
/SCL: U1.36 (IO22), U6.5 (SCL)
/SCL2: U1.10 (IO25), U5.3 (SCL)
/SDA: U1.33 (IO21), U6.6 (SDA)
/SDA2: U1.9 (IO33), U5.4 (SDA)
/SG90: J4.3, U1.37 (IO23)
/motor_PWM: R11.2, U1.11 (IO26), U7.2 (IN)
/start: SW2.2 (B), U1.23 (IO15)
GND: C1.2, C2.2, C5.2, C6.2, C7.1, C8.2, C9.2, C10.2, C11.2, C12.2, C13.2, C14.2, C15.2, C16.2, C17.2, C18.2, D1.2 (A), J1.2, J2.A1_B12 (GND), J2.B1_A12 (GND), J2.SH1 (SHELL_GND), J2.SH2 (SHELL_GND), J2.SH3 (SHELL_GND), J2.SH4 (SHELL_GND), J3.1, J4.1, J5.1, J6.1, Q1.3 (S), R2.2, R3.2, R4.2, R5.2, R6.2, R11.1, SW1.3 (C), SW1.4 (D), SW2.3 (C), SW2.4 (D), U1.1 (GND), U1.15 (GND), U1.38 (GND), U1.39 (GND), U2.5 (GND), U2.9 (GND), U3.1 (GND), U4.2 (GND), U5.1 (GND), U6.3 (GND), U6.7 (A0), U7.4 (GND), U7.5 (GND), U8.4 (V-)
unnamed: C3.2, R3.1
unnamed: C16.1, R9.2, R10.1
unnamed: C4.2, D1.1 (K), L1.1, U2.1 (SW)
unnamed: C1.1, C6.1, D2.1 (K), U2.7 (VIN)
unnamed: D3.2 (A), L1.2
unnamed: J2.A5 (CC1), R5.1
unnamed: J2.B5 (CC2), R6.1
unnamed: J3.2, U1.25 (IO0)
unnamed: J6.2, U8.1, U8.2 (-)
unnamed: Q1.1 (G), U7.6 (OUT), U7.7 (OUT)
unnamed: R7.2, SW1.1 (A), SW1.2 (B), U1.3 (EN)
unnamed: C4.1, U2.8 (BST)
unnamed: C3.1, U2.3 (COMP)
unnamed: R1.2, R2.1, U2.4 (FB)
unnamed: R4.1, U2.6 (FREQ)
unnamed: C17.1, R10.2, U8.3 (+)
VBUS: D4.2 (A), J2.A4_B9 (VBUS), J2.B4_A9 (VBUS)
VCC: D2.2 (A), J1.1

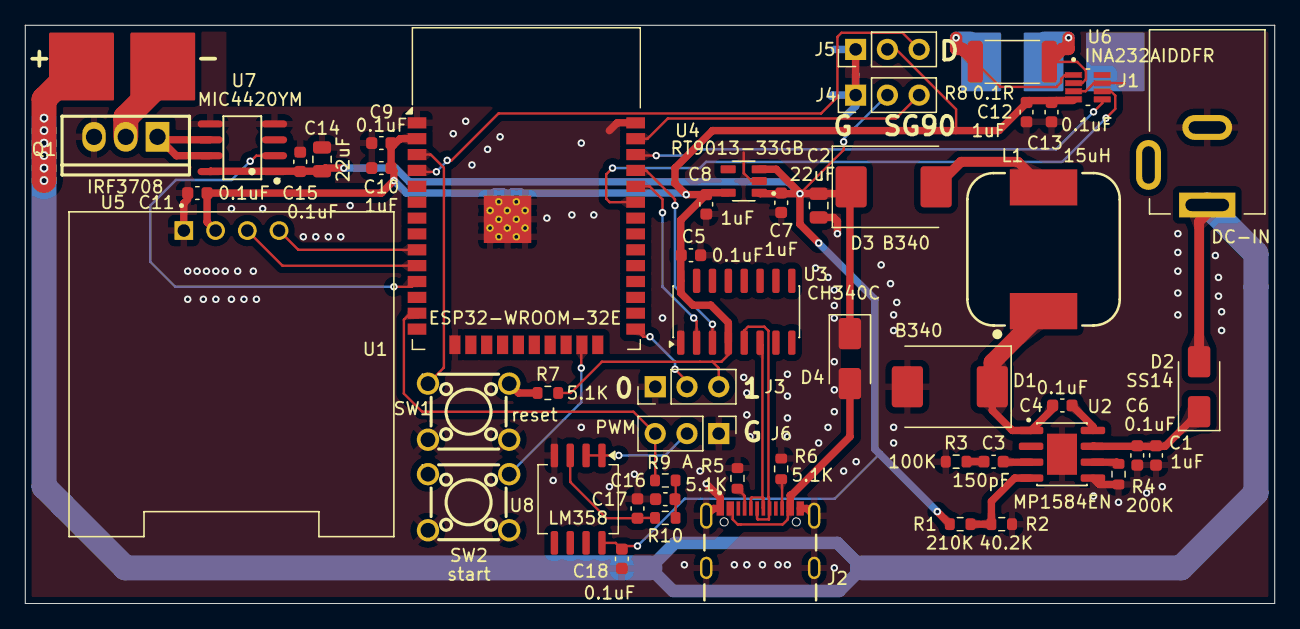
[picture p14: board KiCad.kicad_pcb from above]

Board: 2 copper layers, 100.0 x 46.3 mm, 51 parts (1 on the bottom side), 36 nets.

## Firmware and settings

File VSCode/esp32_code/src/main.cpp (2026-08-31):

#include <Arduino.h>
#include "HardwareSerial.h"
#include "driver/gpio.h"
#include "speed_sensor/speed_sensor.h"
#include "motor_PID/motor_PID.h"
#include "ina232/ina232.h"
#include "board_ui/board_ui.h"
#include "measure_seq/measure_seq.h"
#include "bt_telemetry/bt_telemetry.h"

// ★記憶體保護★：main.cpp 是純粹的「協調 + 顯示」層，對所有共享狀態的存取
// 一律透過 settings.h 提供的介面(speed_get/set_x、pid_get/set_x、ina_get_x、
// ui_get/set_x)；一次要更新好幾個彼此相關欄位(例如 trigger_estop)時，
// 用 SettingsLockGuard 包住整段直接寫欄位，確保其他任務不會讀到只更新一半的狀態。

static constexpr uint32_t SERIAL_DEBUG_MS = 250;
static constexpr uint32_t SERIAL_RPM_MS = 1000;

uint32_t Serial_debug_time;
uint32_t Serial_rpm_time;

static uint8_t last_phase = 0xFF;
static uint8_t last_fault_code = 0xFF;
static bool last_ol_hold = false;
static bool last_ready = false;
static bool last_probe_ready = false;
static bool last_tune_active = false;
static bool last_tune_done = false;
static bool last_speed_stable = false;
static uint8_t last_ui_state = 0xFF;
static uint8_t last_meas_phase = 0xFF;
static bool last_link_lost = false;

// ---- START 鈕(SW2 → IO15，對 GND；板端無外接上拉) ----
static volatile bool start_irq_pending = false;
static uint32_t start_last_accept_ms = 0;
static bool start_raw_last = false;
static bool start_stable = false;
static bool start_prev = false;
static uint32_t start_last_change_ms = 0;

static void IRAM_ATTR start_isr()
{
  start_irq_pending = true;
}

static bool start_raw_pressed()
{
#if START_ACTIVE_LOW
  return digitalRead(START_PIN) == LOW;
#else
  return digitalRead(START_PIN) == HIGH;
#endif
}

static void start_pin_init()
{
  pinMode(START_PIN, INPUT_PULLUP);
  gpio_pullup_en((gpio_num_t)START_PIN);
  gpio_pulldown_dis((gpio_num_t)START_PIN);
  delay(5);

  start_raw_last = start_raw_pressed();
  start_stable = start_raw_last;
  start_prev = start_stable;
  start_last_change_ms = millis();

  attachInterrupt(digitalPinToInterrupt(START_PIN), start_isr, CHANGE);

  Serial.printf("[MAIN] START pin=IO%u pullup ON level=%d pressed=%d "
                "(idle expect level=1; press→0)\n",
                (unsigned)START_PIN, digitalRead(START_PIN), (int)start_raw_pressed());
}

static void trigger_estop()
{
  // 這組欄位代表「已急停」的完整事實，整段上鎖一起寫入
  {
    SettingsLockGuard lock(g_speed_mux);
    settings.fault = true;
    settings.fault_code = FAULT_ESTOP;
    settings.const_speed_ready = false;
    settings.ol_hold = false;
    settings.ol_probe_request = false;
    settings.ol_probe_ready = false;
    settings.init_phase = SPEED_PHASE_FAULT;
    settings.speed_valid = false;
    settings.speed_stable = false;
    settings.ol_pwm_cmd = 0;
  }
  pid_set_autotune_active(false);
  ledcWrite(MOTOR_PWM_PIN, 0);

  ui_set_state(UI_ESTOP);
  Serial.println("[MAIN] ESTOP locked — reboot required");
}

static void start_motor_control()
{
  if (ui_get_motor_started())
  {
    return;
  }
  motor_PID_start();
  speed_sensor_start();
  measure_seq_start(); // 等自動調參後定速穩定，依序驅動安全電流→內阻→曲線計算
  // 這 2 個欄位代表「已啟動」的同一件事，整段上鎖一起寫入
  {
    SettingsLockGuard lock(g_ui_mux);
    ui_settings.motor_started = true;
    ui_settings.state = UI_RUNNING;
  }
  Serial.println("[MAIN] START → motor_PID + speed_sensor + measure_seq started");
}

// 發電機斷線暫停中再按 START：請 measure_seq 從中斷的那一檔／那一點續測（不從頭重跑目前模組）。
// 只負責「轉達使用者意圖」與樂觀更新 UI，實際的恢復時序(等 speed_stable 等)由 measure_seq 自行把關。
static void resume_after_link_loss()
{
  meas_set_resume_requested(true);
  // 使用者已重按 START 確認要續測：先清斷線旗標，避免 loop() 立刻把 UI 打回 LINK_LOST
  // (否則 OLED/上位機會一直顯示「斷線」，即使馬達已開始重新爬升)
  meas_set_link_lost(false);
  ui_set_state(UI_RUNNING);
  Serial.println("[MAIN] START → resume requested after clip/lead pause");
}

// 去彈跳後偵測按下邊緣；ISR 旗標加速喚醒，仍以穩定電平為準
static void handle_start_button(uint32_t now_ms)
{
  if (start_irq_pending)
  {
    start_irq_pending = false;
  }

  const bool raw = start_raw_pressed();
  if (raw != start_raw_last)
  {
    Serial.printf("[MAIN] START raw %d -> %d @%lums (gpio=%d)\n",
                  (int)start_raw_last, (int)raw, (unsigned long)now_ms,
                  digitalRead(START_PIN));
    start_raw_last = raw;
    start_last_change_ms = now_ms;
  }
  else if ((now_ms - start_last_change_ms) >= (uint32_t)START_DEBOUNCE_MS)
  {
    start_stable = start_raw_last;
  }

  const bool edge = (start_stable && !start_prev);
  start_prev = start_stable;
  if (!edge)
  {
    return;
  }

  // 額外保護：兩次有效動作至少間隔 debounce*2
  if ((now_ms - start_last_accept_ms) < (uint32_t)(START_DEBOUNCE_MS * 2))
  {
    return;
  }
  start_last_accept_ms = now_ms;

  const uint8_t cur_state = ui_get_state();
  Serial.printf("[MAIN] START edge accepted, state=%u\n", (unsigned)cur_state);

  if (cur_state == UI_WAIT_START)
  {
    if (!ui_get_motor_started())
    {
      start_motor_control();
    }
    else
    {
      meas_set_restart_requested(true);
      ui_set_state(UI_RUNNING);
      Serial.println("[MAIN] START → new measurement session (no reboot)");
    }
  }
  else if (cur_state == UI_RUNNING)
  {
    // 續測爬升中 UI 已樂觀切成 RUNNING，phase 仍是 LINK_LOST：再按 START 不當急停。
    if (meas_get_phase() == MEAS_LINK_LOST)
    {
      Serial.println("[MAIN] START ignored during resume climb (not ESTOP)");
      return;
    }
    trigger_estop();
  }
  else if (cur_state == UI_LINK_LOST)
  {
    resume_after_link_loss();
  }
}

static const char *phase_name(uint8_t phase)
{
  switch (phase)
  {
  case SPEED_PHASE_STEP_UP:
    return "STEP_UP";
  case SPEED_PHASE_PROBE:
    return "PROBE";
  case SPEED_PHASE_LEARNING:
    return "LEARNING";
  case SPEED_PHASE_READY:
    return "READY";
  case SPEED_PHASE_FAULT:
    return "FAULT";
  case SPEED_PHASE_PID_TUNE:
    return "PID_TUNE";
  case SPEED_PHASE_PID_RUN:
    return "PID_RUN";
  case SPEED_PHASE_PID_PAUSED:
    return "PID_PAUSED";
  default:
    return "UNKNOWN";
  }
}

static const char *fault_name(uint8_t code)
{
  switch (code)
  {
  case FAULT_NONE:
    return "NONE";
  case FAULT_RUNAWAY_RPM:
    return "RUNAWAY_RPM";
  case FAULT_NO_PULSE_TIMEOUT:
    return "NO_PULSE_TIMEOUT";
  case FAULT_PWM_MAX_NO_SPEED:
    return "PWM_MAX_NO_SPEED";
  case FAULT_AUTOTUNE_FAIL:
    return "AUTOTUNE_FAIL";
  case FAULT_ESTOP:
    return "ESTOP";
  case FAULT_MEASURE_SAFETY:
    return "MEASURE_SAFETY";
  default:
    return "UNKNOWN";
  }
}

static const char *ui_state_name(uint8_t st)
{
  switch (st)
  {
  case UI_WAIT_START:
    return "WAIT_START";
  case UI_RUNNING:
    return "RUNNING";
  case UI_ESTOP:
    return "ESTOP";
  case UI_LINK_LOST:
    return "LINK_LOST";
  default:
    return "UNKNOWN";
  }
}

static const char *meas_phase_name(uint8_t ph)
{
  switch (ph)
  {
  case MEAS_IDLE:
    return "IDLE";
  case MEAS_MIN_SPEED_HOLD:
    return "MIN_SPEED_HOLD";
  case MEAS_SAFE_CURRENT:
    return "SAFE_CURRENT";
  case MEAS_RESISTANCE:
    return "RESISTANCE";
  case MEAS_CURVE_CALC:
    return "CURVE_CALC";
  case MEAS_DONE:
    return "DONE";
  case MEAS_LINK_LOST:
    return "LINK_LOST";
  default:
    return "UNKNOWN";
  }
}

static void serial_print_events()
{
  const uint8_t phase = speed_get_init_phase();
  const uint8_t fcode = speed_get_fault_code();
  const bool hold = speed_get_ol_hold();
  const bool ready = speed_get_const_speed_ready();
  const bool probe_rdy = speed_get_ol_probe_ready();
  const uint8_t ui_state_now = ui_get_state();

  if (ui_state_now != last_ui_state)
  {
    Serial.printf("[EVT] ui %s -> %s\n",
                  ui_state_name(last_ui_state), ui_state_name(ui_state_now));
    last_ui_state = ui_state_now;
  }
  if (phase != last_phase)
  {
    Serial.printf("[EVT] phase %s -> %s\n",
                  phase_name(last_phase), phase_name(phase));
    last_phase = phase;
  }
  if (hold != last_ol_hold)
  {
    Serial.printf("[EVT] ol_hold %d -> %d (pwm=%u probe_rpm=%.1f)\n",
                  (int)last_ol_hold, (int)hold,
                  (unsigned)speed_get_ol_pwm_cmd(),
                  (double)speed_get_ol_probe_rpm());
    last_ol_hold = hold;
  }
  if (probe_rdy != last_probe_ready)
  {
    if (probe_rdy)
    {
      Serial.printf("[EVT] probe latched rpm=%.1f (need>=%.1f)\n",
                    (double)speed_get_ol_probe_rpm(),
                    (double)(RPM_INIT_READABLE + RPM_INIT_MARGIN));
    }
    last_probe_ready = probe_rdy;
  }
  if (ready != last_ready)
  {
    Serial.printf("[EVT] const_speed_ready %d -> %d\n",
                  (int)last_ready, (int)ready);
    last_ready = ready;
  }
  const bool tune_active_now = pid_get_autotune_active();
  if (tune_active_now != last_tune_active)
  {
    Serial.printf("[EVT] autotune_active %d -> %d\n",
                  (int)last_tune_active, (int)tune_active_now);
    last_tune_active = tune_active_now;
  }
  const bool tune_done_now = pid_get_autotune_done();
  if (tune_done_now != last_tune_done)
  {
    Serial.printf("[EVT] autotune_done %d -> %d (Kp=%.5f Ki=%.5f Kd=%.5f)\n",
                  (int)last_tune_done, (int)tune_done_now,
                  (double)pid_get_Kp(), (double)pid_get_Ki(),
                  (double)pid_get_Kd());
    last_tune_done = tune_done_now;
  }
  const bool speed_stable_now = speed_get_speed_stable();
  if (speed_stable_now != last_speed_stable)
  {
    Serial.printf("[EVT] speed_stable %d -> %d (rpm=%.1f keep=%.1f)\n",
                  (int)last_speed_stable, (int)speed_stable_now,
                  (double)speed_get_now_speed(), (double)pid_get_keep_rpm());
    last_speed_stable = speed_stable_now;
  }
  if (fcode != last_fault_code)
  {
    if (speed_get_fault())
    {
      Serial.printf("[EVT] FAULT code=%u (%s) rpm=%.1f pwm=%u\n",
                    (unsigned)fcode, fault_name(fcode),
                    (double)speed_get_now_speed(),
                    (unsigned)speed_get_ol_pwm_cmd());
    }
    else if (last_fault_code != 0xFF)
    {
      Serial.printf("[EVT] fault cleared\n");
    }
    last_fault_code = fcode;
  }

  const uint8_t meas_phase_now = meas_get_phase();
  if (meas_phase_now != last_meas_phase)
  {
    Serial.printf("[EVT] measure_seq %s -> %s\n",
                  meas_phase_name(last_meas_phase), meas_phase_name(meas_phase_now));
    last_meas_phase = meas_phase_now;
  }
  const bool link_lost_now = meas_get_link_lost();
  if (link_lost_now != last_link_lost)
  {
    Serial.printf("[EVT] gen link_lost %d -> %d\n", (int)last_link_lost, (int)link_lost_now);
    last_link_lost = link_lost_now;
  }
}

static void serial_print_debug_status()
{
  Serial.printf(
      "[DBG] t=%lu ui=%s start=%d/%d phase=%s rpm=%.1f valid=%d pwm=%u hold=%d "
      "probe_req=%d probe_rdy=%d probe_rpm=%.1f "
      "settle=%u/%u ready=%d ol_hold_ok=%d speed_stable=%d fault=%d(%s) edges=%lu "
      "keep=%.1f tune=%d/%d tunedNVS=%d Kp=%.4f Ki=%.4f Kd=%.4f "
      "V=%.2f I=%.3f P=%.2f ina=%d/%d p=%d n=%lu\n",
      (unsigned long)millis(),
      ui_state_name(ui_get_state()),
      digitalRead(START_PIN),
      (int)start_raw_pressed(),
      phase_name(speed_get_init_phase()),
      (double)speed_get_now_speed(),
      (int)speed_get_speed_valid(),
      (unsigned)speed_get_ol_pwm_cmd(),
      (int)speed_get_ol_hold(),
      (int)speed_get_ol_probe_request(),
      (int)speed_get_ol_probe_ready(),
      (double)speed_get_ol_probe_rpm(),
      (unsigned)speed_get_settle_samples(),
      (unsigned)READY_SETTLE_MIN_SAMPLES,
      (int)speed_get_const_speed_ready(),
      (int)speed_get_rpm_stable(),
      (int)speed_get_speed_stable(),
      (int)speed_get_fault(),
      fault_name(speed_get_fault_code()),
      (unsigned long)speed_get_edge_count(),
      (double)pid_get_keep_rpm(),
      (int)pid_get_autotune_active(),
      (int)pid_get_autotune_done(),
      (int)pid_get_tuned(),
      (double)pid_get_Kp(),
      (double)pid_get_Ki(),
      (double)pid_get_Kd(),
      (double)ina_get_bus_V(),
      (double)ina_get_current_A(),
      (double)ina_get_power_W(),
      (int)ina_get_online(),
      (int)ina_get_data_valid(),
      (int)ina_get_current_plausible(),
      (unsigned long)ina_get_sample_count());
}

void setup()
{
  Serial.begin(115200);
  delay(200);
  Serial.println();
  Serial.println("[BOOT] ESP32 micro-generator firmware");
  Serial.printf("[BOOT] init_need_rpm>=%.1f settle=%ums probe_timeout=%ums "
                "pwm_step=%.0f%% max_ol=%.0f%% runaway=%.0f\n",
                (double)(RPM_INIT_READABLE + RPM_INIT_MARGIN),
                (unsigned)MOTOR_STEP_SETTLE_MS,
                (unsigned)MOTOR_PROBE_TIMEOUT_MS,
                (double)(MOTOR_PWM_STEP_RATIO * 100.0f),
                (double)(MOTOR_STARTUP_PWM_MAX_RATIO * 100.0f),
                (double)RPM_RUNAWAY_MAX);
  Serial.printf("[BOOT] PID autotune en=%d every_boot=%d settle=%us test=%us "
                "samples=%u step=%.0f%% rule=NoOvershoot_PI action=direct5T pmode=pOnError "
                "gain_units=real verbose=%d\n",
                (int)PID_AUTOTUNE_ENABLE, (int)PID_AUTOTUNE_EVERY_BOOT,
                (unsigned)PID_TUNE_SETTLE_SEC, (unsigned)PID_TUNE_TEST_SEC,
                (unsigned)PID_TUNE_SAMPLES,
                (double)(PID_TUNE_STEP_RATIO * 100.0f),
                (int)PID_TUNE_SERIAL_VERBOSE);
  Serial.printf("[BOOT] tune_estop=%.0f pre_settle=%ums gain_scale=%.2f "
                "slew_max=%u/cycle trans_gain=%.2f trans_slew=%u trans_max=%ums "
                "speed_filter_alpha=%.2f load_R=%.1fΩ\n",
                (double)(RPM_RUNAWAY_MAX * PID_TUNE_ESTOP_RATIO),
                (unsigned)PID_TUNE_PRE_SETTLE_MS,
                (double)PID_TUNE_GAIN_SCALE,
                (unsigned)PID_OUTPUT_SLEW_MAX,
                (double)PID_TRANSIENT_GAIN_SCALE,
                (unsigned)PID_TRANSIENT_SLEW_MAX,
                (unsigned)PID_TRANSIENT_MAX_MS,
                (double)SPEED_FILTER_ALPHA,
                (double)LOAD_TEST_RESISTOR_OHM);
  Serial.printf("[BOOT] I2C OLED=soft INA=soft@%uHz | INA addr=0x%02X Rshunt=%.3fΩ Imax=%.2fA\n",
                (unsigned)I2C_INA_FREQ_HZ,
                (unsigned)INA232_I2C_ADDR,
                (double)INA232_RSHUNT_OHM, (double)INA232_IMAX_A);
  Serial.println("[BOOT] START handled in main; UI is display-only");

  Serial_debug_time = millis();
  Serial_rpm_time = millis();

  start_pin_init();
  board_ui_oled_init();
  board_ui_start();
  ina232_start();
  bt_telemetry_start();
  Serial.println("[BOOT] tasks started (board_ui display + ina232 + bt_telemetry)");
}

void loop()
{
  const uint32_t now = millis();

  // START：起動 / 急停
  handle_start_button(now);

  // 其他模組 fault → UI 跟著進急停畫面
  if ((ui_get_state() == UI_RUNNING) && speed_get_fault())
  {
    ui_set_state(UI_ESTOP);
  }

  // 量測序列偵測到夾子／量測線鬆脫且馬達已暫停 → UI 進入(非故障的)暫停畫面。
  // 必須同時看 pause_request：續測恢復期間 pause_request 已放行、link_lost 已清除，
  // 不應再把 UI 打回 LINK_LOST(否則 OLED 無反應、上位機異常彈窗不會消失)。
  if (meas_get_link_lost() && meas_get_pause_request())
  {
    if (ui_get_state() == UI_RUNNING)
    {
      ui_set_state(UI_LINK_LOST);
    }
  }

  serial_print_events();

  if (now - Serial_debug_time >= SERIAL_DEBUG_MS)
  {
    serial_print_debug_status();
    Serial_debug_time = now;
  }

  if (now - Serial_rpm_time >= SERIAL_RPM_MS)
  {
    Serial.println(speed_get_now_speed());
    Serial_rpm_time = now;
  }

  // ★關鍵：loop() 之前完全沒有任何讓出 CPU 的呼叫(無 delay/yield)，
  // 會把 Core1 的 IDLE 任務餓死 → 觸發 Task Watchdog，造成週期性長時間卡頓
  // (訊息斷斷續續、間隔越來越長，且 START 按鍵在卡頓期間完全偵測不到)。
  // 1ms 對按鈕手動操作毫無影響，但足以餵飽 WDT、讓排程恢復正常。
  vTaskDelay(pdMS_TO_TICKS(1));
}

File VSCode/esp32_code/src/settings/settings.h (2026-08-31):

#pragma once
#include <Arduino.h>
#include <Preferences.h>       // 用於將變數存入FLASH
#include "freertos/FreeRTOS.h" // portMUX_TYPE / 臨界區(自旋鎖)API，記憶體保護介面用
// 常數設定

// speed_sensor.h
#define buf_idx_bit 4                    // 環形緩衝深度位元數 → 2^4 = 16 筆時間戳
#define space_number 2                   // 用於測速之光柵盤總格數(遮光/透光格對數，依實際光柵修改)
#define EDGES_PER_REV (space_number * 2) // 雙沿觸發時，每一整圈的邊緣數

// 定速就緒門檻：控制迴路實際使用的轉速一律採用「同位置整圈」量測(rpm_from_same_slot)，
// 本身就用同一物理光柵位置抵銷每格加工誤差，不需要額外的格距誤差學習/補償；
// 這裡只保留一個簡單的樣本數門檻，確保開環固定 PWM 後至少觀察幾圈、EMA 濾波值
// 已收斂，才允許離開 LEARNING 進入 READY / 定速
#define READY_SETTLE_MIN_SAMPLES 24 // 開環固定 PWM 後，至少觀察幾圈才允許進入 READY / 定速
#define SPEED_STALL_TIMEOUT_MS 300  // 超過此時間無新邊緣 → 視為停轉/無法可靠量測

// 診斷用(不影響控制邏輯)：PID_RUN 定速期間偵測異常事件並印一次 [EVT]，方便日後排查
// 轉速忽然跳變/收斂變慢等現象時，快速判斷是感測端訊號問題還是馬達真實物理擾動
#define SPEED_JUMP_WARN_RPM 120    // 單一測速週期(read_space)轉速變化超過此值視為異常，印警告
#define SPEED_EDGE_GAP_WARN_MS 100 // 定速中連續無新邊緣超過此時間(仍未達 stall 判定)視為異常，印警告

// 感測端離群值抑制：高轉速時光柵偶發假邊緣/漏跳會讓「同位置整圈」瞬間算出離譜轉速，
// 若直接餵進 EMA→PID，會出現「轉速突然飆高再慢慢回落」的假性抽搐(馬達負載未變)。
// 下列閾值只丟棄明顯不合理的單筆樣本，不影響真實的漸進加速/減速。
#define SPEED_OUTLIER_MAX_ABS_RPM 180.0f   // 單筆 rpm_same 與目前 EMA 差超過此值(RPM)
#define SPEED_OUTLIER_MAX_RATIO 0.14f        // 或超過目前 EMA 的此比例(取兩者較寬鬆者)
#define SPEED_OUTLIER_REJECT_MAX 3           // 連續拒絕幾筆後強制接受(避免真實大階躍被永遠擋住)

// 邊緣去彈跳(debounce)：光柵訊號偶爾會有機械彈跳/雜訊造成極短間隔的假觸發，
// 對「整圈平均」影響很小(分母大)，但會讓「單格補償」算出離譜的瞬時轉速(分母只有 1/4 圈)。
// 兩次觸發間隔對應轉速若超過 RPM_RUNAWAY_MAX×此倍數，視為雜訊直接在 ISR 丟棄、不計入。
#define MIN_EDGE_TICKS_SAFETY_RPM_MULT 2.5f

// 「同位置整圈」量測法可正常讀取的最低轉速門檻(對應舊版約 1000RPM 失靈現象) + 餘量
#define RPM_INIT_READABLE 1000.0f
#define RPM_INIT_MARGIN 150.0f

// 階梯開環起動：升一次 PWM → 等待穩定 → 擷取第一筆可用轉速
#define MOTOR_PWM_STEP_RATIO 0.05f        // 每次升高的 duty 佔最大輸出比例
#define MOTOR_STEP_SETTLE_MS 250          // 每次升 PWM 後等待穩定的時間(ms)
#define MOTOR_PROBE_TIMEOUT_MS 400        // settle 後等待第一筆可用轉速的逾時(ms)，逾時視為 0 並再升階
#define MOTOR_STARTUP_PWM_MAX_RATIO 0.70f // 開環起動允許的最大 duty 比例

// 失控保護
#define RPM_RUNAWAY_MAX 17000.0f // 轉速超過此值視為飛車，立即切斷輸出

// ★馬達通電看門狗(單一閾值，涵蓋馬達通電全過程，無空窗)：
// 只要 ol_pwm_cmd>0(馬達有 PWM 輸出——從剛按下 START 的第一階開環升速，
// 到就緒觀察、自動調參、定速運行，全程都算)，且連續此時間內完全沒有
// 新脈衝進來，立即緊急停止鎖定(需重開機)。
// 從馬達一啟動就開始計時、全程持續生效，不會有「還沒等到某個階段」或
// 「已經動過一次就永久失效」之類的空窗——任何時刻卡死(卡死/斷軸/感測器
// 故障/接線脫落等)都會在此時限內被抓到。
// 5Ω 負載通斷是階躍擾動：轉速會瞬間掉/衝，光柵脈衝間隔會暫時拉長，
// 但不代表卡死。門檻需大於「負載階躍後 PID 把轉速拉回可讀區」的最長無脈衝空窗，
// 又遠短於真的卡死。請依實測「按下 START 到第一次脈衝」與「接負載後最大脈衝間隔」
// 抓安全餘量；數值愈小保護愈即時，但也愈容易在負載階躍時誤判。
#define NO_PULSE_TIMEOUT_MS 800

// PID 自動調參(sTune)：速度感測器調教完成(const_speed_ready)後執行
// 注意：本機台 PWM→RPM 增益極大(小小的佔空比變化就能造成數千 RPM 變化)，
// 快速的『反曲點法(IP)』很容易被步階響應中的震盪/超調騙到過大的製程增益，
// 進而算出過度激進、會在 0↔滿載間來回硬切換的 PID 參數，故改用：
//   1) 完整 5T 測試(direct5T)取代反曲點法(directIP)，較不怕響應有震盪
//   2) NoOvershoot_PI 規則(只用 P+I，不含 D)取代傳統 Ziegler-Nichols(較不激進)：
//      QuickPID 內部把 Kd 換算成每輪增益是「Kd / 取樣秒數」，而定速閉環取樣週期
//      (read_space)僅 15ms，若含 D 項會被放大達數百倍，量測轉速的正常雜訊就足以
//      讓輸出在 0↔滿載間反覆硬切換、永遠無法收斂；改用純 PI 規則從根源避開此問題
//      (此製程 Tau/DeadTime 比值高，sTune 自評「easy to control」，PI 已足夠)
//   3) 較小的測試步階(貼近實際工作點附近的線性區)
//   4) 依目前轉速動態估計 inputSpan，而非直接套用飛車保護的絕對上限
//   5) 額外乘上安全係數(PID_TUNE_GAIN_SCALE)做保守化
//   6) ★把 sTune 的無因次增益換算回真實工程單位★
//      sTune 內部的製程增益是 (ΔPV/inputSpan)/(ΔCO/outputSpan)，是無因次的，
//      它推導出的 Kp 也是「正規化增益」；但 QuickPID 吃的是真實單位(RPM→PWM count)，
//      兩者差 inputSpan/outputSpan 倍。本機台 inputSpan≈5000RPM、outputSpan=1023count，
//      比值高達約 4.9，直接套用會讓 Kp 放大近 5 倍而逼近臨界增益，必定劇烈震盪。
//      (sTune 官方範例的 inputSpan/outputSpan 多半數量級相近、比值≈1，所以不會踩到)
//      實際換算與重算規則見 motor_PID.cpp 的 sTune::tunings 分支
#define PID_AUTOTUNE_ENABLE 1           // 1=啟用自動調參
#define PID_AUTOTUNE_EVERY_BOOT 1       // 1=每次上電都調；0=僅 NVS 尚未 tuned 時調一次
#define PID_TUNE_SETTLE_SEC 3           // 調參前在 outputStart 穩定秒數
#define PID_TUNE_TEST_SEC 25            // 開環步階測試時間上限(秒)；5T 法需約 5×Tau，寧可抓寬鬆
#define PID_TUNE_SAMPLES 250            // 測試取樣點數(建議 200~500)
#define PID_TUNE_STEP_RATIO 0.08f       // 相對目前開環 duty 再升的比例(佔 max PWM)；愈小愈接近目標點附近的線性區
#define PID_TUNE_INPUT_SPAN_MIN 2000.0f // sTune 輸入(RPM)全幅估計下限，實際值於執行期依目前轉速動態估算
#define PID_TUNE_ESTOP_RATIO 0.75f      // 調參期間緊急停止門檻 = RPM_RUNAWAY_MAX × 此比例(較保守)
#define PID_TUNE_PRE_SETTLE_MS 500      // 測速就緒後，先等待此時間讓濾波轉速真正收斂，再鎖定 keep_rpm / 開始測試
#define PID_TUNE_GAIN_SCALE 0.8f        // 對算出的 Kp/Ki/Kd 額外乘上的安全係數(<1 更保守)
// NoOvershoot_PI 的閉環迴路增益 = Kp×製程增益 = 0.35×(Tau/死時間)，只由可控性比值決定。
// 萬一某次量到異常小的死時間(雜訊或取樣抖動)會讓迴路增益暴衝而震盪，故對此比值設上限；
// 20 對應迴路增益 7，對 Tau/td 已屬「很好控制」的系統而言仍相當保守
#define PID_TUNE_TAU_DEAD_RATIO_MAX 20.0f
#define PID_TUNE_TOTAL_TIMEOUT_MARGIN_SEC 10 // 整段調參(settle+test)之外再加的總時長保險絲，逾時視為失敗並斷電
#define PID_TUNE_SERIAL_VERBOSE 1            // 1=調參時印進度/sTune 摘要；0=僅關鍵事件
#define PID_TUNE_SERIAL_MS 500               // 調參進度列印間隔(ms)
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

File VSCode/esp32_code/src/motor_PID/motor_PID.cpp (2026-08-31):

#include "motor_PID.h"
#include <sTune.h>

// 算完脈衝數後用於呼叫PID任務的旗標實體
TaskHandle_t xPIDTaskHandle = NULL;
// 載入設定
volatile motor_PID PID_settings{};
// 快照用變數
static float pid_output;          // 輸出到驅動主動力馬達PWM的定時器值
static float pid_input_bridge;    // 輸入到PID模組的(RPM)
static float pid_setpoint_bridge; // 要維持的值(RPM)
// PWM最大值限制
// ★注意：這裡是 C++ 全域變數的靜態初始化，發生在 setup()/所有 RTOS 任務啟動之前，
// 當下只有目前這個執行緒在跑、不會有人同時寫入 PID_settings，故直接讀欄位即可，
// 刻意不透過 pid_get_pwm_res()：跨編譯單元(settings.cpp)的鎖初始化順序沒有保證
// 一定早於這裡執行，為了不要引入不必要的「靜態初始化順序」風險，這一行維持原樣。
float max_pwm_value = (float)((1 << PID_settings.pwm_res) - 1);

// 階梯開環狀態
static uint16_t step_pwm = 0;       // 目前階梯 duty
static uint32_t settle_start_ms = 0; // 本次升階後開始等待的時間
static bool settling = false;       // 是否處於「升階後等待穩定」
static bool step_applied = false;   // 本階 PWM 是否已寫出

// sTune 自動調參
static bool tuner_configured = false;
static float tune_kp = 0.0f;
static float tune_ki = 0.0f;
static float tune_kd = 0.0f;
static uint32_t tune_sample_hits = 0;   // 進入 sample 狀態次數(進度估計)
static uint32_t tune_last_print_ms = 0; // 上次進度列印時間
static float tune_out_start = 0.0f;
static float tune_out_step = 0.0f;
static float tune_input_span = 0.0f;    // 本次調參用的 sTune 輸入全幅(換算真實單位增益時要用)
static uint32_t tune_start_ms = 0;      // 本次調參開始時間(用於總時長保險絲)
static bool tune_ready_seen = false;    // 測速剛就緒的旗標(用於 pre-settle 等待)
static uint32_t tune_ready_since_ms = 0;

// 定速閉環輸出斜率限制：避免每個控制週期都在 0↔滿載間硬切換
static uint16_t last_final_pwm = 0;

// 轉速穩調判定狀態
static uint8_t speed_stable_hits = 0;
static float last_keep_rpm_seen = -1.0f;

// 負載通斷 / 換轉速檔的短暫增益排程(只在 PID_RUN 生效)
static bool pid_transient_active = false;
static uint32_t pid_transient_start_ms = 0;
static bool pid_load_seen = false;
static bool pid_last_load_connected = false;
static float last_keep_for_gain = -1.0f;
static uint8_t pid_assist_hits = 0;
static uint8_t pid_transient_exit_hits = 0;

// ★記憶體保護★：本檔案對 settings/PID_settings 的存取一律透過 settings.h 提供的
// 介面——單一欄位讀寫用 speed_get_x()/set_x()、pid_get_x()/set_x()；需要「一次原子
// 讀寫好幾個相關欄位」的狀態轉換(例如 trip_fault、調參結果落地)則用 SettingsLockGuard
// 包住整段直接存取欄位。務必注意：settings 用 g_speed_mux、PID_settings 用 g_pid_mux，
// 兩個不同的鎖，程式中任何地方都不會巢狀同時持有兩者，避免交叉鎖死的風險。
// 暫態增益只讀 meas_get_load_connected()(g_meas_mux)，讀完即放，不會與 g_pid_mux /
// g_speed_mux 同時持有。

// 強制清除對外穩調旗標(初始化/故障/換目標/未就緒時呼叫)
static void clear_speed_stable()
{
    speed_set_speed_stable(false);
    speed_stable_hits = 0;
}

// 僅在 PID 閉環正常運行時更新 speed_stable
static void update_speed_stable()
{
    const float keep_rpm_now = pid_get_keep_rpm();
    const float now_speed = speed_get_now_speed();

    // 換目標：立刻視為未穩，重新計數
    if (fabsf(keep_rpm_now - last_keep_rpm_seen) > 0.5f)
    {
        last_keep_rpm_seen = keep_rpm_now;
        clear_speed_stable();
    }

    const bool system_ok =
        (!speed_get_fault()) &&
        speed_get_const_speed_ready() &&
        pid_get_autotune_done() &&
        (!pid_get_autotune_active()) &&
        (speed_get_init_phase() == SPEED_PHASE_PID_RUN) &&
        speed_get_speed_valid() &&
        (now_speed >= SPEED_STABLE_MIN_RPM) &&
        (keep_rpm_now > 1.0f);

    if (!system_ok)
    {
        clear_speed_stable();
        return;
    }

    const float err = fabsf(now_speed - keep_rpm_now);
    const float ref = fmaxf(now_speed, keep_rpm_now);
    const float abs_eps = (float)SPEED_STABLE_ABS_EPS +
                          keep_rpm_now * ((float)SPEED_STABLE_ABS_EPS_PER_1000RPM / 1000.0f);
    const bool near_target =
        (err <= abs_eps) ||
        ((ref > 1.0f) && ((err / ref) <= (float)SPEED_STABLE_REL_EPS));

    if (near_target)
    {
        if (speed_stable_hits < 255)
        {
            speed_stable_hits++;
        }
        if (speed_stable_hits >= SPEED_STABLE_NEED_HITS)
        {
            speed_set_speed_stable(true);
        }
    }
    else
    {
        // 還沒穩到新目標 / 偏離目標 → 立刻 false
        clear_speed_stable();
    }
}

static void pid_read_base_gains(float &kp, float &ki, float &kd)
{
    SettingsLockGuard lock(g_pid_mux);
    kp = PID_settings.Kp;
    ki = PID_settings.Ki;
    kd = PID_settings.Kd;
}

static void pid_apply_base_tunings(QuickPID &myPID)
{
    float kp, ki, kd;
    pid_read_base_gains(kp, ki, kd);
    myPID.SetTunings(kp, ki, kd);
}

static void pid_apply_transient_tunings(QuickPID &myPID)
{
    float kp, ki, kd;
    pid_read_base_gains(kp, ki, kd);
    myPID.SetTunings(kp * (float)PID_TRANSIENT_GAIN_SCALE,
                     ki * (float)PID_TRANSIENT_GAIN_SCALE,
                     kd);
}

static void pid_exit_transient(QuickPID &myPID, const char *why)
{
    if (!pid_transient_active)
    {
        return;
    }
    pid_transient_active = false;
    pid_assist_hits = 0;
    pid_transient_exit_hits = 0;
    pid_apply_base_tunings(myPID);
    Serial.printf("[PID] transient gain OFF (%s)\n", why);
}

static void pid_enter_transient(QuickPID &myPID, uint32_t now_ms, const char *why,
                                bool load_on_ff, bool restart_timer)
{
    if (!pid_transient_active)
    {
        // 進暫態當下立刻清穩調：負載剛切時轉速還沒掉，speed_stable 可能仍為 true，
        // 若不先清，同一輪結尾就會誤判「已穩」而立刻退回原增益。
        clear_speed_stable();
        pid_transient_active = true;
        pid_transient_start_ms = now_ms;
        pid_transient_exit_hits = 0;
        pid_apply_transient_tunings(myPID);
        Serial.printf("[PID] transient gain ON (%s) x%.2f slew=%u\n",
                      why, (double)PID_TRANSIENT_GAIN_SCALE,
                      (unsigned)PID_TRANSIENT_SLEW_MAX);
    }
    else if (restart_timer)
    {
        // 負載通斷／換檔是新的真實擾動：重算 8s 上限。誤差輔助不得每輪刷新，否則永遠退不出。
        pid_transient_start_ms = now_ms;
        pid_transient_exit_hits = 0;
    }
    if (load_on_ff)
    {
        const float bumped = fminf(pid_output + (float)PID_LOAD_ON_PWM_BUMP, max_pwm_value);
        pid_output = bumped;
        last_final_pwm = (uint16_t)bumped;
    }
}

static void pid_reset_transient_state(QuickPID *myPID)
{
    if (pid_transient_active && myPID != nullptr)
    {
        pid_exit_transient(*myPID, "reset");
    }
    else
    {
        pid_transient_active = false;
    }
    pid_load_seen = false;
    last_keep_for_gain = -1.0f;
    pid_assist_hits = 0;
    pid_transient_exit_hits = 0;
}
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

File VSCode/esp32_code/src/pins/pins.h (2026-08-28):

#pragma once

// GPIO36 (VP). Older docs used SENSOR_VP; esp32dev pins_arduino.h only defines A0 (=36).
#define SPEED_SENSOR_PIN 36
#define MOTOR_PWM_PIN 26
// ★2026 量測序列改版：已拿掉變速箱與可變負載，SERVO_PIN 不再驅動 SG90，
// 改為數位輸出控制外接 MOSFET 開關(高電位＝把 LOAD_TEST_RESISTOR_OHM 固定
// 測試負載接上發電機)，供安全電流／內阻兩模組共用。沿用原巨集名稱不改名，
// 詳見 settings.h 的 LOAD_SWITCH_* 常數與 measure_seq 模組。
#define SERVO_PIN 23
// BUCK_PWM_PIN 目前未被任何模組使用(原可變負載相關功能已移除)，保留給日後 MPPT/buck 使用。
#define BUCK_PWM_PIN 14

// ★依 KiCad PCB 實際網路(曾與直覺命名對調)：
//   OLED 模組 → /SDA2 /SCL2 → ESP32 IO33 / IO25
//   INA232 U6 → /SDA  /SCL  → ESP32 IO21 / IO22 (A0→GND → I2C 0x40)
#define SDA_PIN 33  // OLED SDA (/SDA2)
#define SCL_PIN 25  // OLED SCL (/SCL2)
#define SDA2_PIN 21 // INA232 SDA (/SDA；板端無外接上拉 → 軟體 I2C 用內部上拉)
#define SCL2_PIN 22 // INA232 SCL (/SCL)
#define START_PIN 15

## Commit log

2026-05-23 Add .gitignore for KiCad and development tools
2026-05-23 增加了ESP32核心的原理圖及PCB(不含供電)
    [KiCad.kicad_pcb, KiCad.kicad_sch]
2026-05-23 彻底移除KiCad临时文件，让.gitignore生效
2026-05-23 提交初始BOM表
    [BOM.XLSX, KiCad.kicad_pcb, KiCad.kicad_sch]
2026-05-23 删除KiCad临时文件：autosave、backup、lock
2026-05-23 更新.gitignore：忽略KiCad的autosaved和backup文件夹
2026-05-23 移除已被追踪的KiCad自动保存文件夹
2026-05-23 提交修正後的.gitignore，修正#auto_saved_files#被上傳問題
2026-05-23 測試提交
2026-05-23 刪除#auto_saved_files#
2026-05-24 完成主電源輸入轉到數位系統主電源軌電壓(12~24v to 5v)之原理圖，包含外部DC供電接口
    [KiCad.kicad_pcb, KiCad.kicad_sch]
2026-05-24 完成主電源輸入轉到數位系統主電源軌電壓模塊(12~24v to 5v)之PCB
    [KiCad.kicad_pcb, KiCad.kicad_sch]
2026-05-25 更新BOM表
    [BOM.XLSX]
2026-05-25 完成5v電源軌的所有電路
    [KiCad.kicad_pcb, KiCad.kicad_sch]
2026-05-25 新增5V轉3.3V電源軌元件及防反接電路所需元件
    [BOM.XLSX]
2026-05-25 完成5V轉3.3V電源軌元件及防反接電路、ESP32復位電路、優化主電源輸入轉5V的電路、USB轉TTL完整迴路之原理突及PCB
    [KiCad.kicad_pcb, KiCad.kicad_sch]
2026-05-26 新增了vscode及3D_print_Component資料夾的自述文件
2026-05-26 完成esp32的燒錄/工作模式選擇電路之原理圖與PCB
    [KiCad.kicad_pcb, KiCad.kicad_sch]
2026-05-26 補全mcu供電去偶電容
    [KiCad.kicad_pcb, KiCad.kicad_sch]
2026-05-26 放置0.96吋OLED在園裡圖
2026-05-26 放置0.96吋OLED
    [KiCad.kicad_pcb, KiCad.kicad_sch]
2026-05-26 增加0.96'OLED(已完成原理圖及PCB)及開始測試按鈕(只添加到PCB，原理圖未連接)
    [KiCad.kicad_pcb, KiCad.kicad_sch]
2026-05-26 完成start按鈕的原理圖/PCB連接
    [KiCad.kicad_pcb, KiCad.kicad_sch]
2026-05-26 修正OLED之SDA/SCL連接錯誤
    [KiCad.kicad_pcb, KiCad.kicad_sch]
2026-05-26 新增功率測量IC之原理圖及PCB(未連接)
    [KiCad.kicad_pcb]
2026-05-26 連接功率計IC的供電，新增MOS及驅動IC(未連接)
    [KiCad.kicad_pcb, KiCad.kicad_sch]
2026-05-27 完成pcb(除了DAC部分)
    [KiCad.kicad_pcb, KiCad.kicad_sch]
2026-05-27 補全功率測量迴路之電路
    [KiCad.kicad_pcb, KiCad.kicad_sch]
2026-05-29 修改iic走線，將原本共用同一組iic的裝置分別接到兩不同的iic
    [KiCad.kicad_pcb, KiCad.kicad_sch]
2026-05-29 完成PCB及原理圖所有的連接
    [KiCad.kicad_pcb, KiCad.kicad_sch]
2026-05-30 移除大面積焊盤上方的阻焊層
    [KiCad.kicad_pcb]
2026-05-30 增大外露銅箔接點之面積以利焊接
    [KiCad.kicad_pcb]
2026-05-30 增加Gerber製版文件
    [KiCad.kicad_pcb]
2026-05-30 修正被焊盤阻斷的絲印
    [KiCad.kicad_pcb]
2026-05-30 修改斯絲印位置
    [KiCad.kicad_pcb]
2026-05-30 完成bom表單
    [BOM.XLSX, KiCad.xlsx]
2026-05-30 更新README.md，新增ESP32_MPPT系統說明及文件架構；新增BOM及KiCad資料夾的README.md
2026-05-30 更新README.md，調整文件架構部分的格式，增加換行以提升可讀性
2026-05-30 新增多個README文件，包含專案結構及使用說明；新增.gitignore及platformio.ini配置文件；實作main.cpp及單元測試目錄
2026-05-30 更新 README.md
2026-05-31 新增ESP32速度傳感器功能，包含初始化函數及引腳定義，更新main.cpp以整合速度傳感器初始化，並新增clangd配置以改善IntelliSense支持。
2026-05-31 而成PINS.H
2026-05-31 修改速度感測模組的實現代碼
2026-06-01 完成測速模組(編譯未過)
2026-06-01 完成speed_sensor,h/.cpp
2026-06-01 更新環境
2026-06-01 補全pins.h
2026-06-01 新增簡單測試代碼
2026-06-02 嵌入freeRTOS以方便管理
2026-06-02 完善speed_sensor的延時方式，並新增motor_PID模組，且做了過去模組對RTOS的優化
2026-06-03 完成算完脈衝後即呼叫pid模組的功能
2026-06-04 初始化PWM函數
2026-06-04 更新reame.md
2026-06-07 增加變速箱之基礎齒輪
    [ESP32_MPPT_TEST.FCStd]
2026-06-07 修正reame.md之錯字
2026-06-08 更新readme.md
    [ESP32_MPPT_TEST.FCStd]
2026-06-08 更新自述文件
2026-06-08 新增電路中mic4420ym之驅動腳位下拉電阻
    [KiCad.kicad_pcb, KiCad.kicad_sch, KiCad.xlsx]
2026-06-08 更新自述文件，準備公開
2026-06-08 在自述文件說明進度
2026-06-08 增加授權說明條款
2026-06-08 修改自述文件
2026-06-10 更新自述文件及變速箱
2026-06-10 回復自述文件舊版本
2026-06-10 Update README to clarify KiCad folder description
2026-06-11 新增快照
    [KiCad.kicad_pcb]
2026-06-13 新增光柵
    [ESP32_MPPT_TEST-主體.stl]
2026-06-13 重新編寫測速模組底層代碼（未完成）
2026-06-15 完成speed_sensor模組的重建
2026-06-19 配置pid模塊
    [1_0-1.stl, 1_0-M.stl, 1_1.stl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]
2026-06-25 繪製3d模型
    [ESP32_MPPT_TEST.FCStd]
2026-07-27 新增上位機資料夾，包含免安裝執行檔、環境設置腳本及相關配置文件，並更新.gitignore以排除不必要的檔案。新增3D模型及測速模組的相關代碼，並更新README以說明資料夾結構與使用說明。
    [ESP32_MPPT-主體.stl, ESP32_MPPT.FCStd]
2026-08-07 基礎定速與外設完成
    [ESP32_MPPT.FCStd, KiCad.kicad_pcb, KiCad.kicad_sch]
2026-08-28 完成發電機特性量測流程與上位機藍牙監控
    新增安全電流、內阻與曲線計算韌體模組，藍牙遙測與量測狀態機；上位機支援藍牙配對、即時監控、PDF 報表與重連改善。排除本機打包產物與個人設定。
2026-08-31 收尾為微型發電機測試機：完成韌體量測與免安裝上位機，並清掉不該進倉庫的環境與本機資料。
